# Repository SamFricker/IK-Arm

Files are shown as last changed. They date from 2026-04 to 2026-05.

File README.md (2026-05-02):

# Inverse Kinematics Robotic Arm

## Overview

This project documents the development of a 3 degrees of freedom robotic arm, from initial CAD design through physical construction and inverse kinematics-based control.

The goal was to design, build, and program a system capable of moving its end effector to a target position by computing the required joint angles. The repository captures the complete engineering process, combining mechanical design, hardware integration, and software implementation.

The rough working and step by step documentation can be viewed on the google slides link below

---

## Links
[Google slides](https://docs.google.com/presentation/d/11Yj7fBU4LIVXhnzH5_TuppZ-_PNuySzZH2yjffFqX7w/edit?usp=sharing)

[Onshape CAD file](https://cad.onshape.com/documents/37680dd26e3a28759b563309/w/ac908424e809403c105aca99/e/9a8b1e70a123fc365e53a634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)

### Google slides contain All rough working
---

## Final Build

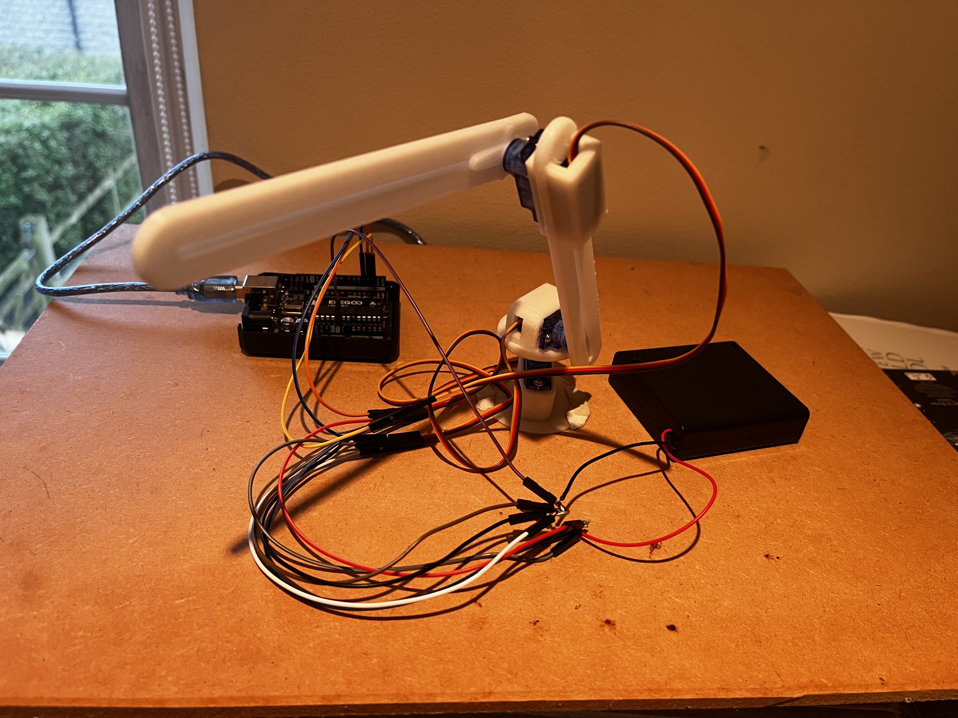
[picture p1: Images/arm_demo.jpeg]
Robotic Arm Demo


## Demo Video (Click to play)

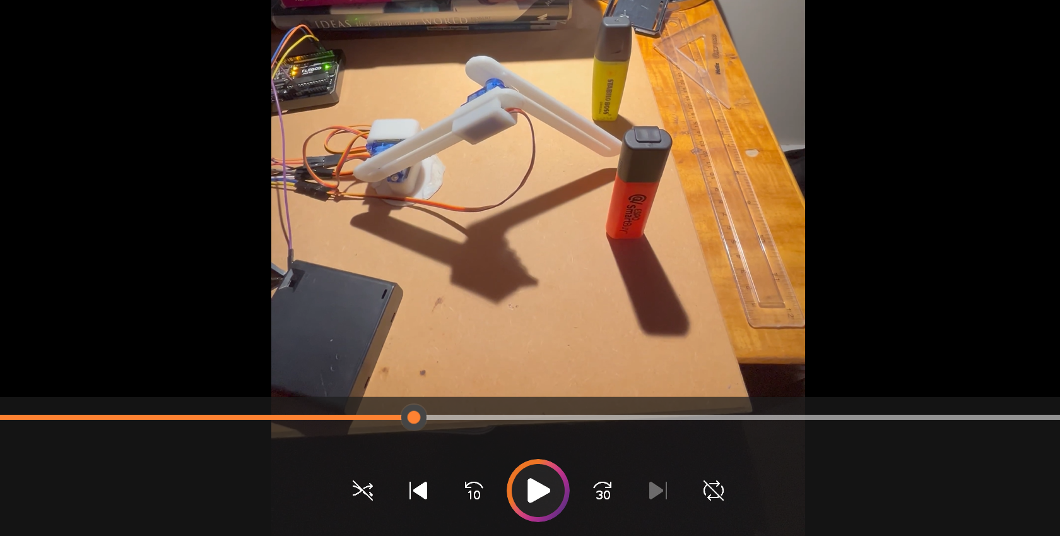
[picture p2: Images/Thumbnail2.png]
IK Demo Video thumbnail (https://youtube.com/shorts/bh-hIgJWgIE)


## CAD Model

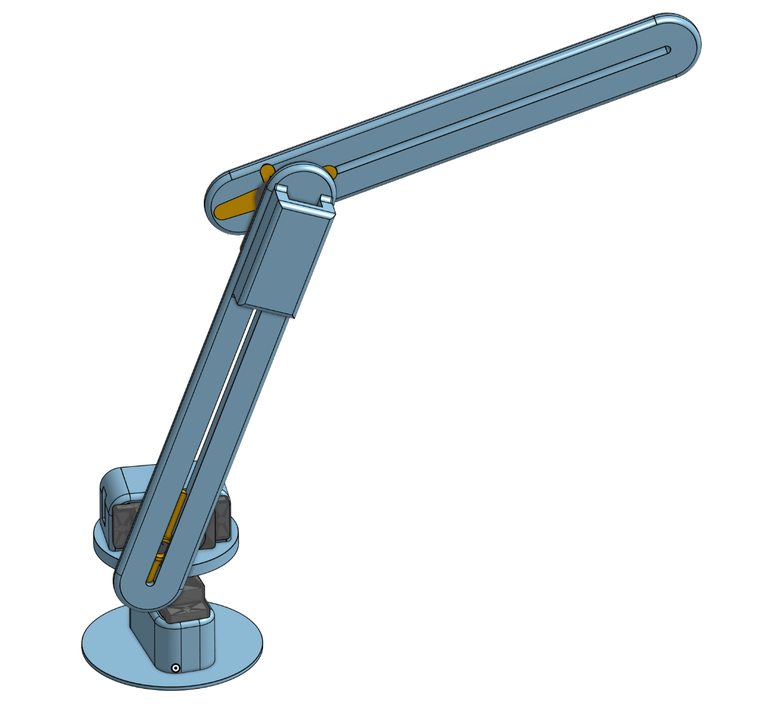
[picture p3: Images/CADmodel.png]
CAD Model


---

## Features

* 3 DOF robotic arm design
* Real time control with keyboard
* Inverse kinematics for target coordinate positioning
* Physical build and assembly
* Visual / real-world demonstration of motion

---

## Design & Build

The mechanical structure of the arm was designed using Onshape CAD software, with consideration for joint movement, stability, range of motion, weight and material cost. The build process involved assembling the physical components and integrating actuators to enable controlled movement.

---

## Kinematics

The system uses inverse kinematics:

* **Inverse kinematics:** computes joint angles required to reach a target position.

The inverse kinematics implementation allows the arm to move toward specified coordinates, demonstrating the relationship between joint space and Cartesian space.

The servos used for this project were inexpensive and not fit for application, they only had speed control capabilities, were very low torque, seemed to operate at different speeds forward and backwards, and all operated at different speeds (despite being programmed to move at the same speed). This meant many software methods had to be employed to overcome the hardware shortage, mainly the calculation for the delay when the servo would be moving, such that it would move through a set angle, this involved linear interpolation and experimental timing results. Additionally the highest moment bearing servo varied in speed significantly when moving vertically, therefore a linearly interpolated constant was added to servo movement time based on calculated maximum moment of the device and current moment. 

---

## What I Learned

* Applying kinematic theory to a real system
* Bridging CAD design and physical construction
* Integrating hardware with control software
* Debugging real-world constraints vs theoretical models

---

## Future Improvements

* Increase degrees of freedom
* Improve positioning accuracy
* Add UI for real life control
* Use higher resolution actuators with built in angle and speed controllers
* Implement obstacle avoidance

---

## Reflections 

The final device works well in all three degrees of freedom, with only 180 degrees of operating area due to the algorithms limitations (unable to support negative values of x in arctan and arccos functions), future adaptations may include a ‘for’ command in the programme to account for negative x values.
The overall design is extremely light and allows for fast movement of the servos however it has limited strength for lifting objects. Additionally, the designs biggest flaw is that the motors are not precisely calibrated and therefore with multiple movements, error in the angle of each joint accumulates. To fix both of these issues, and updated device should use high torque 180 degree rotational servos rather than 360 degree continuous servos, this would require a higher voltage power supply and a redesign of the CAD model.
Moment calculations worked very well and fixed the issue of servo two stalling under load.

---

## License

This project is licensed under the MIT License.

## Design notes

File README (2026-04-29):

# Inverse Kinematics Robotic Arm

## Overview

This project documents the development of a 3 degrees of freedom robotic arm, from initial CAD design through physical construction and inverse kinematics-based control.

The goal was to design, build, and program a system capable of moving its end effector to a target position by computing the required joint angles. The repository captures the complete engineering process, combining mechanical design, hardware integration, and software implementation.

The rough working and step by step documentation can be viewed on the google slides link below

---

## Links

* google slide documenting process: https://docs.google.com/presentation/d/11Yj7fBU4LIVXhnzH5_TuppZ-_PNuySzZH2yjffFqX7w/edit?usp=sharing
* Onshape CAD file: https://cad.onshape.com/documents/37680dd26e3a28759b563309/w/ac908424e809403c105aca99/e/9a8b1e70a123fc365e53a634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

---

## Demo

Robotic Arm Demo

Demo video of the final response to inputted coordinates: (Videos\IK_Demo.MOV)

Real time control demo: (Videos\ManualControl_Demo.mov)

CAD model: (Images\CADmodel.png)

---

## Features

* 3 DOF robotic arm design
* Real time control with keyboard
* Inverse kinematics for target coordinate positioning
* Physical build and assembly
* Visual / real-world demonstration of motion

---

## Project Structure

```bash
IK-Arm/
├── CAD/        # 3D models and design files
├── Code/       # C++ control and kinematics implementation
├── Images/     # Screenshots and demo media
├── Videos/     # Recordings of demonstrations
├── README.md
```

---

## Design & Build

The mechanical structure of the arm was designed using Onshape CAD software, with consideration for joint movement, stability, range of motion, weight and material cost. The build process involved assembling the physical components and integrating actuators to enable controlled movement.

---

## Kinematics

The system uses inverse kinematics:

* **Inverse kinematics:** computes joint angles required to reach a target position.

The inverse kinematics implementation allows the arm to move toward specified coordinates, demonstrating the relationship between joint space and Cartesian space.

The servos used for this project were inexpensive and not fit for application, they only had speed control capabilities, were very low torque, seemed to operate at different speeds forward and backwards, and all operated at different speeds (despite being programmed to move at the same speed). This meant many software methods had to be employed to overcome the hardware shortage, mainly the calculation for the delay when the servo would be moving, such that it would move through a set angle, this involved linear interpolation and experimental timing results. Additionally the highest moment bearing servo varied in speed significantly when moving vertically, therefore a linearly interpolated constant was added to servo movement time based on calculated maximum moment of the device and current moment. 

---

## Setup & Usage

1. Clone the repository:

```bash
git clone <https://github.com/SamFricker/IK-Arm>
cd IK-arm
```

2. Build the project:

```bash
g++ code/main.cpp -o arm
```

3. Run:

```bash
./arm
```

---

## What I Learned

* Applying kinematic theory to a real system
* Bridging CAD design and physical construction
* Integrating hardware with control software
* Debugging real-world constraints vs theoretical models

---

## Future Improvements

* Increase degrees of freedom
* Improve positioning accuracy
* Add UI for real life control
* Use higher resolution actuators with built in angle and speed controllers
* Implement obstacle avoidance

---

## Reflections 

The final device works well in all three degrees of freedom, with only 180 degrees of operating area due to the algorithms limitations (unable to support negative values of x in arctan and arccos functions), future adaptations may include a ‘for’ command in the programme to account for negative x values.
The overall design is extremely light and allows for fast movement of the servos however it has limited strength for lifting objects. Additionally, the designs biggest flaw is that the motors are not precisely calibrated and therefore with multiple movements, error in the angle of each joint accumulates. To fix both of these issues, and updated device should use high torque 180 degree rotational servos rather than 360 degree continuous servos, this would require a higher voltage power supply and a redesign of the CAD model.
Moment calculations worked very well and fixed the issue of servo two stalling under load.

---

## License

This project is licensed under the MIT License.

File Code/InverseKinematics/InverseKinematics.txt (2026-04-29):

#include <Servo.h>
// This code should be used to control a robotic arm using inverse kinematics, 
//it takes coordinate values in the defined coordinate space before calculateing
//and actuating the end effector movement to those coordinates.
// Author: Sam Fricker
// Date: 20/12/2025

// initialise servos as variables
Servo elbow;
Servo shoulder;
Servo base;

// allocate variables calculated through experiment for each servo to move through 90 degrees
float s3_90 = 1100; //times for a 90 degree rotation
float s2_90 = 730;
float s1_90 = 1460;

// allocate initial starting positions
float phi = 0; // angle of s3 (starting position straight up)
float theta = 90; // angle of s2 (starting position straight up)
float alpha = 0; // base angle 

// command variables of angles which each servo must rotate through
float s1Angle;
float s2Angle;
float s3Angle; 

// useful constants
long double pi = 3.141592653589793238462643383279502884197;
float momentMax = 27075.6; // maximum moment calculated using CAD model(g*mm) 
float moment = ((105*16*9.81*cos(theta*pi/180))+(125+55)*cos((phi)*pi/180)*6*9.81*cos((theta - phi)*pi/180)); // initial moment

// add an increment for when the servo is moving up or down against its movement for the time delay
float upincrement = 300;
float downincrement = 60;

// introduce coordinate variables
float x = 0;
float y = 235; //mm
float z = 0;

// lengths of each arm
float l1 = 110; //mm
float l2 = 125; 

// assign the servos to each pin in arduino and start serial monitor
void setup() {
  elbow.attach(2); 
  shoulder.attach(3);
  base.attach(4);
  Serial.begin(9600);
}

// begin main operating loop
void loop() {
  // get desired coordinate values from serial
  if (Serial.available() > 0) {

    String input = Serial.readStringUntil(' ');
    // filter through coordinates broken up by commas
    int firstCommaIndex = input.indexOf(',');
    int secondCommaIndex = input.indexOf(',', firstCommaIndex + 1);

    // If both commas exist, extract x, y, and z values
    if (firstCommaIndex > 0 && secondCommaIndex > firstCommaIndex) {
      String xString = input.substring(0, firstCommaIndex);
      String yString = input.substring(firstCommaIndex + 1, secondCommaIndex); 
      String zString = input.substring(secondCommaIndex + 1);

      x = xString.toInt();
      y = yString.toInt();
      z = zString.toInt();

      Serial.print("x = ");
      Serial.println(x);
      Serial.print("y = ");
      Serial.println(y);
      Serial.print("z = ");
      Serial.println(z);
    }

    // provided the coorniates lie within a 235 mm radius circle, move end effector to desired point.
    if (sqrt(sq(x) + sq(y) + sq(z)) <= 235){
      
      // calculate target angles using inverse kinematics
      float targetalphaRAD = (atan(z/x));
      float targetphiRAD = (-acos((sq(x)+sq(y)-sq(l1)-sq(l2))/(2*l1*l2)));
      float targetThetaRAD = abs(atan(y/x)+atan((l1*sin(targetphiRAD))/(l1+l2*cos(targetphiRAD))));

      //convert to degrees
      float targetalpha = targetalphaRAD *180/pi;
      float targetphi = targetphiRAD *180/pi;
      float targetTheta = targetThetaRAD *180/pi;

      // print the desired angles to check kinematics is working
      Serial.print("targetalpha = ");
      Serial.println(targetalpha);
      Serial.print("targetphi = ");
      Serial.println(targetphi);
      Serial.print("targetTheta = ");
      Serial.println(targetTheta);

      // calculate angles to move through
      s1Angle = alpha - (targetalpha);
      s2Angle = theta - (targetTheta); // negative = anticlockwise, positive = clockwise
      s3Angle = phi - (targetphi);

      // print the angles which the servos must move through
      Serial.print("s1Angle = ");
      Serial.println(s1Angle);
      Serial.print("s2Angle = ");
      Serial.println(s2Angle);
      Serial.print("s3Angle = ");
      Serial.println(s3Angle);

      //Base movement
      if (s1Angle >= 0){
        base.write(83); // set speed of servo (speed chosen experimentally where 90 is stationary)
        delay(abs((s1Angle/90)*s1_90)); // delay for linearly interpolated ammount of time
        base.write(90); // stop movement
        alpha = (targetalpha); // set angle to target
      } else if (s1Angle < 0){
        base.write(100); // Set speed in angle direction 
        delay(abs((s1Angle/90)*s1_90)); // delay for linearly interpolated ammount of time
        base.write(90); // stop movement
        alpha = (targetalpha); // set angle to target
      }

      //Servo #2 movement
      if (s2Angle >= 0){
        // set speed in angle direction
        shoulder.write(80);
        // time delay must be linearly interpolated depending on angle with a constant added that depends on moment
        if (moment >= 0){
          delay(abs((s2Angle/90)*s2_90 - (moment/momentMax) * downincrement));
        } else if (moment < 0){
          delay(abs((s2Angle/90)*s2_90 - (moment/momentMax) * upincrement));
        }

        shoulder.write(90); // stop servo
        theta = (targetTheta); // update angle

      } else if (s2Angle < 0){
        shoulder.write(100);

        if (moment >= 0){
          delay(abs((s2Angle/90)*s2_90 + (moment/momentMax) * upincrement));
        } else if (moment < 0){
          delay(abs((s2Angle/90)*s2_90 + (moment/momentMax) * downincrement));
        }

        shoulder.write(90);
        theta = (targetTheta);
      }

      //Servo #3 Movement 
      if (s3Angle <= 0){
        elbow.write(80); // set speed in appropriate direction
        delay(abs((s3Angle/90)*s3_90)); // linear interpolation with angle for time delay
        elbow.write(90); // stop servo
        phi = (targetphi); // update angle
      } else if (s3Angle > 0){
        elbow.write(100);
        delay(abs((s3Angle/90)*s3_90));
        elbow.write(90);
        phi = (targetphi);
      }
      // recalculate moment after each movement.
      moment = ((105*16*9.81*cos(theta*pi/180))+(125+55)*cos((phi)*pi/180)*6*9.81*cos((theta - phi)*pi/180)); // range: +/-max
    }

    // print out anlges to troubleshoot
    Serial.print("phi = ");
    Serial.println(phi);
    Serial.print("theta = ");
    Serial.println(theta);
    Serial.print("alpha = ");
    Serial.println(alpha);
    Serial.print("moment (g*mm) = ");
    Serial.println(moment);
    Serial.println("------------------");
  }
}

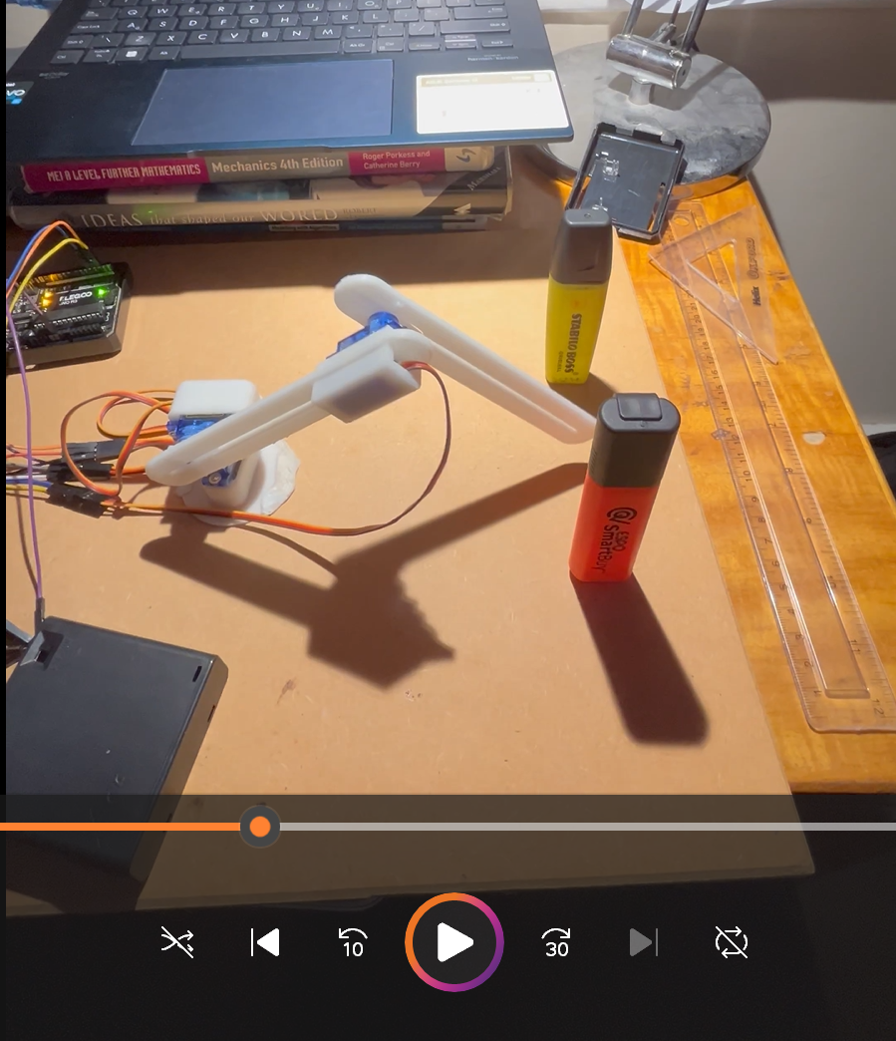
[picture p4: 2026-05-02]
Images/Thumbnail.png

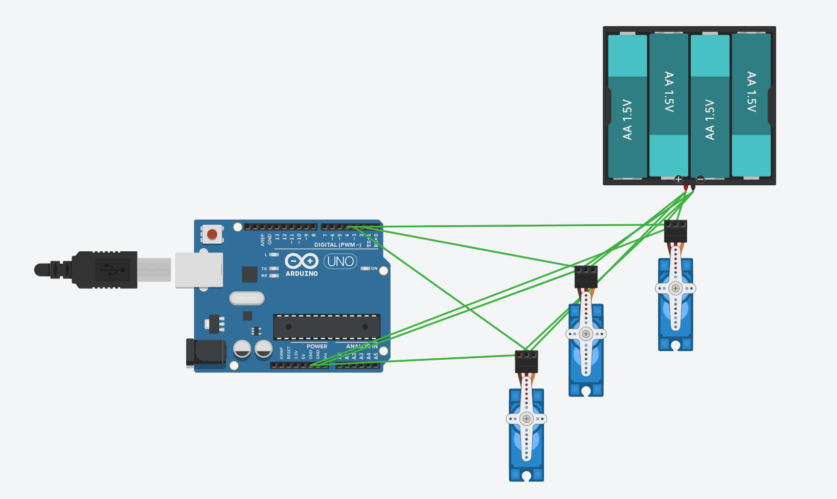
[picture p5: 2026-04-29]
Images/CircuitDiagram.png

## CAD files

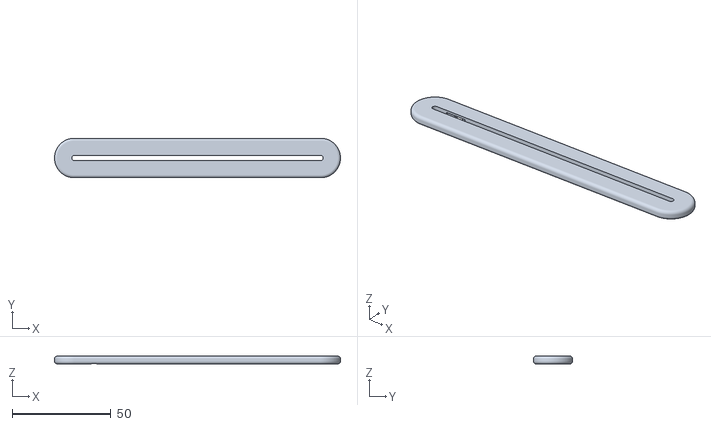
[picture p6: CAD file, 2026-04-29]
CAD/ARM 2.stl
145.0 x 20.0 x 4.00

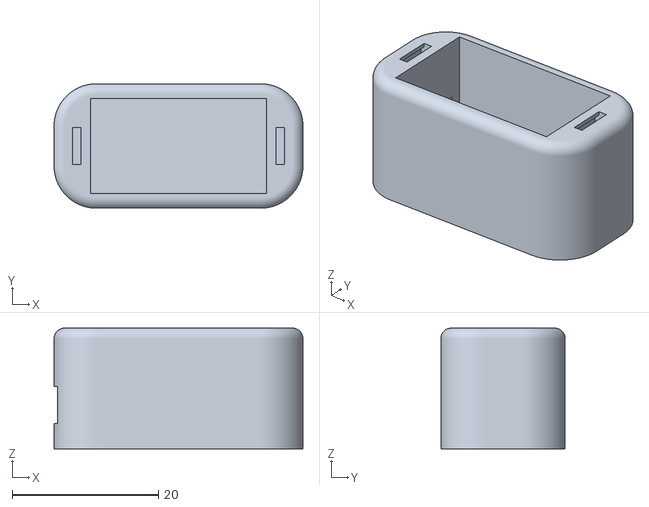
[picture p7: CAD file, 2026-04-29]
CAD/Servo cast.stl
34.0 x 17.0 x 16.5

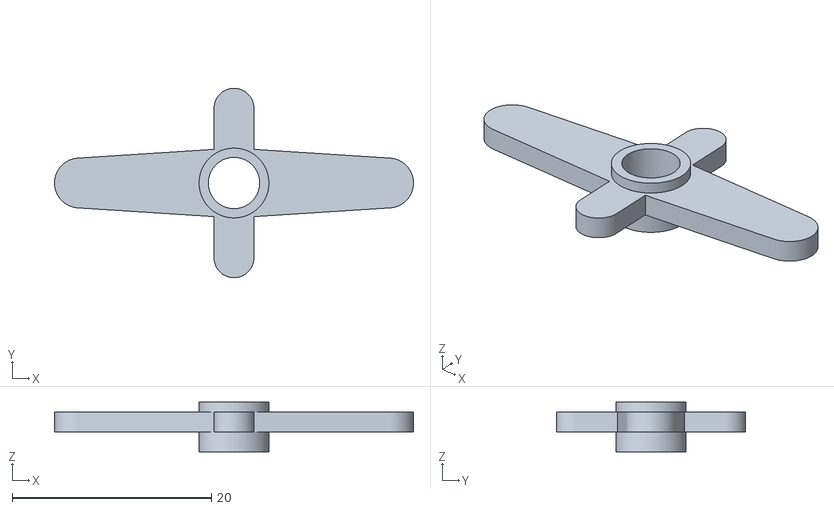
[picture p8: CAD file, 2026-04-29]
CAD/Rotor.stl
36.0 x 19.0 x 5.00

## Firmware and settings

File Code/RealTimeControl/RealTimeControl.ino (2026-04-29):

// RealTimeControl is code for an arduino that should be used to control a robotic arm with the keyboard of the powering computer 
#include <Servo.h> // include servo library to control servo motors

// assign servos names of joint positions
Servo elbow;    // servo controlling elbow joint (s3)
Servo shoulder; // servo controlling shoulder joint (s2)
Servo base;     // servo controlling base rotation (s1)

// experimentally determined times for a 90 degree rotation at speeds
float s3_90 = 1100; //delay (ms) for elbow to rotate 90 degrees
float s2_90 = 730;  //delay (ms) for shoulder to rotate 90 degrees
float s1_90 = 1460; //delay (ms) for base to rotate 90 degrees

// initialise starting position angles
float phi = 90;   // angle of s3 (starting position straight up)
float theta = 90; // angle of s2 (starting position straight up)
float alpha = 0;  // base angle (starting facing forward)

// command variables of angles which each servo must rotate through
float s1Angle; // commanded rotation for base
float s2Angle; // commanded rotation for shoulder
float s3Angle; // commanded rotation for elbow

//constants
long double pi = 3.141592653589793238462643383279502884197; // high precision value of pi for calculations
float momentMax = 27075.6; //calculated maximum value of moment (g*mm)
float moment = ((105*16*9.81*cos(theta*pi/180))+(125+55)*cos((90-phi)*pi/180)*6*9.81*cos((theta + phi - 90)*pi/180)); // initial moment based on starting angles

// experimentally determined time increments to counteract moments
float upincrement = 300;   // additional delay when lifting against gravity
float downincrement = 30;  // reduced delay when moving with gravity

// assign servos to each pin and start serial monitor
void setup() {
  elbow.attach(2);    // attach elbow servo to pin 2
  shoulder.attach(3); // attach shoulder servo to pin 3
  base.attach(4);     // attach base servo to pin 4
  Serial.begin(9600); // begin serial communication at 9600 baud
}

// start main operating loop
void loop() {

  // get serial input as a number between 1 and 9
  if (Serial.available() > 0) { // check if data is available from serial
    String input = Serial.readStringUntil('\n'); // read full input until newline
    char v = input[0]; // first character determines command type
    String angleStr = input.substring(1); // remaining string represents angle value

    //S3

    if (v == '5') {
      elbow.write(90);    // reset elbow to neutral position
      shoulder.write(90); // reset shoulder to neutral position
      base.write(90);     // reset base to neutral position
    } else if (v == '4'){
      s3Angle = angleStr.toFloat(); // convert input angle to float
      elbow.write(80); // move elbow in one direction
      delay((s3Angle/90)*s3_90); // scale delay proportionally to desired angle
      elbow.write(90); // stop movement
      phi = (phi + s3Angle); // update stored elbow angle
    } else if (v == '6'){
      s3Angle = angleStr.toFloat(); // convert input angle to float
      elbow.write(100); // move elbow in opposite direction
      delay((s3Angle/90)*s3_90); // scale delay proportionally to desired angle
      elbow.write(90); // stop movement
      phi = (phi - s3Angle); // update stored elbow angle
    }

    //S2
    
    if (v == 'y'){
      s2Angle = angleStr.toFloat(); // convert input angle to float
      shoulder.write(80); // move shoulder upward direction
      if (moment >= 0){
        delay((s2Angle/90)*s2_90 - (moment/momentMax) * downincrement); // adjust delay based on load assisting motion
      } else if (moment < 0){
        delay((s2Angle/90)*s2_90 - (moment/momentMax) * upincrement); // adjust delay when working against load
      }
      shoulder.write(90); // stop movement
      theta = theta - s2Angle; // update stored shoulder angle
    } else if (v == 'r'){
      s2Angle = angleStr.toFloat(); // convert input angle to float
      shoulder.write(100); // move shoulder downward direction
      if (moment >= 0){
        delay((s2Angle/90)*s2_90 + (moment/momentMax) * upincrement); // adjust delay when lifting load
      } else if (moment < 0){
        delay((s2Angle/90)*s2_90 + (moment/momentMax) * downincrement); // adjust delay when load assists motion
      }
      shoulder.write(90); // stop movement
      theta = theta + s2Angle; // update stored shoulder angle
    }

    //Base

    if (v == 'd'){
      s1Angle = angleStr.toFloat(); // convert input angle to float
      base.write(83); // rotate base in one direction
      delay((s1Angle/90)*s1_90); // scale delay based on angle
      base.write(90); // stop movement
      alpha = (alpha - s1Angle); // update stored base angle
    } else if (v == 'g'){
      s1Angle = angleStr.toFloat(); // convert input angle to float
      base.write(100); // rotate base in opposite direction
      delay((s1Angle/90)*s1_90); // scale delay based on angle
      base.write(90); // stop movement
      alpha = (alpha + s1Angle); // update stored base angle
    }

    moment = ((105*16*9.81*cos(theta*pi/180))+(125+55)*cos((90-phi)*pi/180)*6*9.81*cos((theta + phi - 90)*pi/180)); // recalculate moment after movement (range: +/-max)

    Serial.println("------------------"); // separator for readability in serial monitor
    Serial.print("phi = "); // label for elbow angle
    Serial.println(phi); // print elbow angle
    Serial.print("theta = "); // label for shoulder angle
    Serial.println(theta); // print shoulder angle
    Serial.print("alpha = "); // label for base angle
    Serial.println(alpha); // print base angle
    Serial.print("moment (g*mm) = "); // label for calculated moment
    Serial.println(moment); // print current moment value
  }

}
